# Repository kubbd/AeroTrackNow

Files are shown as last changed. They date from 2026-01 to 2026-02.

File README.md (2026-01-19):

# AeroTrackNow CanSat (Teensy 4.0)

## Project overview
This repo holds the flight and ground code for a guided CanSat with parafoil steering. It’s built around a Teensy 4.0 and a LoRa link, with a simple Python ground station on the PC.

## Flight system
The flight stack runs on a Teensy 4.0 and includes:

- Predictive landing guidance (steers to make predicted landing converge to target)
- GNSS (ZED-X20P) with RTK passthrough (Teensy forwards RTCM bytes to GNSS)
- LoRa (SX1262) bidirectional:
  - receive TARGET once
  - receive RTK continuously
  - send telemetry @ 1 Hz
- BMP280: pressure + temperature (and sink-rate estimate)
- BNO085: accelerometer + rotation vector (drop detection + heading)
- Dual-servo differential steering
- No buzzer

## Ground station
The ground station has two pieces that work together:

- **Ground radio node (Teensy + SX1262):** a USB-to-LoRa bridge.
- **PC ground station (Python):** reads telemetry, validates CRC, and shows the key numbers.

A Teensy is used on the ground because the SX1262 is an SPI radio that needs tight timing and interrupt handling. The Teensy handles those hardware details and exposes a simple USB serial link to the PC.

### USB serial ports (Teensy + optional RTK source)
Both the Teensy ground radio node and the RTK correction source plug into your laptop over USB. They show up as **two separate serial ports**, and you tell the ground station which is which with CLI flags.

- `--port` is **always** the Teensy ground radio node.
- `--rtk-port` is **optional** and is only for RTK correction input.
- RTK is optional — the system runs fine without it.

**USB device → CLI argument**

| USB device | CLI argument |
| --- | --- |
| Teensy ground radio node | `--port` |
| RTK correction source (optional) | `--rtk-port` |

**Examples**

Without RTK:
```
python3 ground_station_advanced.py --port /dev/ttyACM0 --target-lat 39.1234567 --target-lon -104.9876543 --target-alt 1850.0
```

With RTK:
```
python3 ground_station_advanced.py --port /dev/ttyACM0 --rtk-port /dev/ttyUSB0 --target-lat 39.1234567 --target-lon -104.9876543 --target-alt 1850.0
```

## Radio architecture
The ground radio node is intentionally “transparent.” It just moves bytes and doesn’t care about packet formats.

**What the firmware does:**
- Initialize SX1262 via RadioLib with the same pin mapping as flight hardware.
- Forward any USB serial bytes to LoRa (transparent transmit).
- Forward any LoRa packet bytes to USB (transparent receive).
- Operate non-blocking so serial and radio remain responsive.

**What the firmware does not do:**
- Parse packets or enforce application formats.
- Add CRC or message framing.
- Buffer or reorder payloads beyond RadioLib’s receive buffer.

**Data Flow Diagram (textual):**
PC (Python) ⇄ USB ⇄ Teensy 4.0 ⇄ SPI ⇄ SX1262 ⇄ Air ⇄ CanSat

## Folder structure
- `firmware/` – Teensy Arduino sketch
- `docs/` – pinout, telemetry, state machine docs
- `hardware/` – put KiCad files/netlists here

## How to get started
1. Skim `docs/TELEMETRY.md`, `docs/PINOUT.md`, and `docs/STATE_MACHINE.md` to understand the data formats and wiring.
2. Build and upload the flight firmware from `firmware/cansat_flight.ino`.
3. Build and upload the ground radio firmware from `firmware/ground_radio_teensy.ino`.
4. Run the Python ground station (`ground_station.py`) on your PC and point it at the Teensy USB port.

## Build instructions
1. Install required Arduino libraries:
   - RadioLib
   - SparkFun u-blox GNSS Arduino Library
   - Adafruit BMP280 Library
   - Adafruit BNO08x
2. Open `firmware/cansat_flight.ino` in Arduino IDE.
3. Select board: **Teensy 4.0**, then upload.

## Tuning parameters
Inside `firmware/cansat_flight.ino`:
- `RANGE_US` (servo throw) – start small, increase carefully
- `KP_TURN`, `MAX_TURN`
- `TERMINAL_HEIGHT_M`, `CAPTURE_RADIUS_M`
- `SERVO_TRIM` (parafoil trim) – change in steps of 0.01..0.02

Inside `cansat_flight_PRODUCTION_v2.ino`:
- `MAG_DECLINATION_DEG` – magnetic declination for the launch site (true-north alignment)
- `IMU_YAW_OFFSET_DEG` – IMU mounting yaw offset (0° if aligned to CanSat X-axis)
- `SINK_GNSS_BLEND_ALPHA` – blend factor for GNSS vertical velocity into sink rate
- `SERVO_RANGE_US`, `SERVO_MAX_RATE`, `SERVO_DEADBAND` – steering authority and responsiveness
- `FINAL_APPROACH_HEIGHT_M`, `FLARE_HEIGHT_M`, `TERMINAL_HEIGHT_M` – terminal guidance gates

**Why trim exists and how to tune it:**
Parafoils usually fly with a slight built-in bias. `SERVO_TRIM` lets you offset the neutral command so the canopy flies straight. Start at 0.0, do a short test glide, and nudge the trim by 0.01–0.02 until it tracks straight with neutral steering.

**How to disable guidance for testing:**
If you want to fly with no steering, set the guidance gains to zero (`KP_TURN = 0` and `MAX_TURN = 0`). The servos will stay neutral and the system will still log and transmit telemetry.

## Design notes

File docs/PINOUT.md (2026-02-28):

# PINOUT (Teensy 4.0)

These are the **actual Teensy pin numbers** (the leading number in the KiCad pin name).

## GNSS (ZED-X20P)
- GNSS UART: **Serial5**
- Teensy **RX** = **21** (GNSS TX1 → Teensy RX)
- Teensy **TX** = **20** (GNSS RX1 ← Teensy TX)
- TPS (optional) = **24** Currently unconnected
- RTKFIX (optional) = **25** Currently unconnected

## I2C (BNO085 + BMP280)
- SDA = **18**
- SCL = **19**

## LoRa (SX1262 / CORE1262-LF)
This module requires controlling the external RF switch using RXEN/TXEN (not DIO2/DIO3), and it may need a slow SPI clock (~500 kHz) for reliable operation.
- SCK = **13**
- MOSI = **11**
- MISO = **12**
- NSS/CS = **10**
- DIO1 = **7**
- RESET = **8**
- BUSY = **9**
- RXEN = **5**
- TXEN = **6**

## SD Card
- SPI shared with LoRa: **SCK/MOSI/MISO = 13 / 11 / 12**
- CS = **23**

## Servos
- Left servo PWM = **3**
- Right servo PWM = **4**

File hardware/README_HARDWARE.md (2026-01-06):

Put KiCad project files, PDFs, and netlists here.

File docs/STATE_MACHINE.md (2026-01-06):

# STATE MACHINE

## States
0. **BOOT**
   - Init sensors, radio, GNSS, SD
   - Servos neutral
   - Wait for TARGET packet

1. **WAIT_FOR_DROP**
   - Servos neutral
   - Wait for drop event
   - Drop detection is gated by descent (**sink_rate > 1.0 m/s**) to avoid rocket-launch false triggers.

2. **WAIT_FOR_STABLE_DESCENT**
   - Servos neutral
   - Wait until sink rate is stable (within band) continuously for ~2.5 s

3. **GUIDED_DESCENT**
   - Predictive guidance active
   - Compute predicted landing point and steer to reduce error

4. **TERMINAL**
   - Servos frozen neutral below terminal height and within capture radius
   - No more steering

5. **LANDED**
   - Servos neutral

## Transitions
- BOOT → WAIT_FOR_DROP: TARGET received
- WAIT_FOR_DROP → WAIT_FOR_STABLE_DESCENT: dropDetected() == true
- WAIT_FOR_STABLE_DESCENT → GUIDED_DESCENT: descentStable() == true
- GUIDED_DESCENT → TERMINAL: height < TERMINAL_HEIGHT_M && predicted error < CAPTURE_RADIUS_M
- TERMINAL → LANDED: landingDetected() == true

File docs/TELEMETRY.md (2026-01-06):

# TELEMETRY (CanSat → Ground)

**Rate:** 1 Hz  
**Transport:** LoRa (SX1262)  
**Encoding:** Binary struct + CRC16-CCITT

## Packet: TelemetryPacket (msgType = 0x03)

| Field | Type | Units / Scale |
|---|---|---|
| msgType | uint8 | 0x03 |
| time_ms | uint32 | milliseconds since boot |
| lat_e7 | int32 | latitude * 1e7 |
| lon_e7 | int32 | longitude * 1e7 |
| height_agl_dm | int16 | (GNSS_alt_MSL - target_alt_MSL) * 10 |
| pressure_hPa_x10 | uint16 | pressure (hPa) * 10 |
| temp_c_x10 | int16 | temperature (°C) * 10 |
| ground_speed_cms | uint16 | ground speed (m/s) * 100 |
| servo_left_x1000 | int16 | command -1000..1000 |
| servo_right_x1000 | int16 | command -1000..1000 |
| pred_lat_e7 | int32 | predicted landing latitude * 1e7 |
| pred_lon_e7 | int32 | predicted landing longitude * 1e7 |
| mission_state | uint8 | state enum |
| crc16 | uint16 | CRC16-CCITT over all prior bytes |

## Incoming packets (Ground → CanSat)

### TargetPacket (msgType = 0x01)
Sent once before drop.

| Field | Type | Units / Scale |
|---|---|---|
| msgType | uint8 | 0x01 |
| tgt_lat_e7 | int32 | latitude * 1e7 |
| tgt_lon_e7 | int32 | longitude * 1e7 |
| tgt_alt_cm | int32 | target altitude MSL (m) * 100 |
| crc16 | uint16 | CRC16-CCITT |

### RTK (msgType = 0x02)
- Byte stream of RTCM3 corrections.
- Teensy **forwards raw bytes** to the GNSS UART.

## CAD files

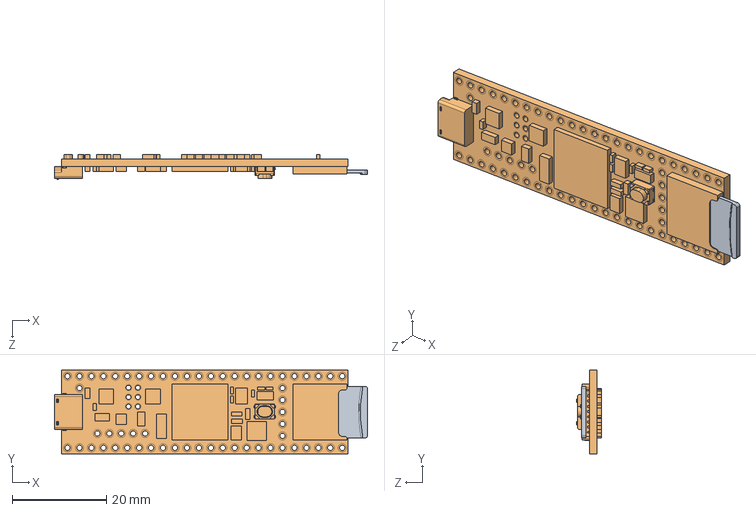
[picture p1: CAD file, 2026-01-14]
hardware/KiCad/Libaries/teensy.pretty-master/Teensy_4.1_Assembly.STEP
66.6 x 17.8 x 5.27 mm

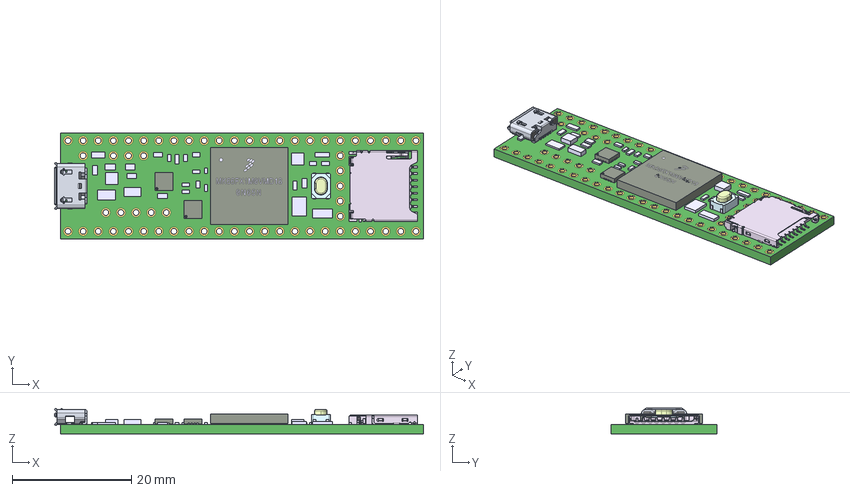
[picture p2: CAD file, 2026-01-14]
hardware/KiCad/Libaries/teensy.pretty-master/Teensy_3.5_3.6_Assembly.STEP
62.0 x 17.9 x 4.29 mm
switch
K66-CHIP
QFN-16 (3x3) Part1 x 2
QFN-16 (3x3) Part2 x 32
micro_usb_47346-0001
TEENSY_3_6_pcb
TEENSY_3_6_passives

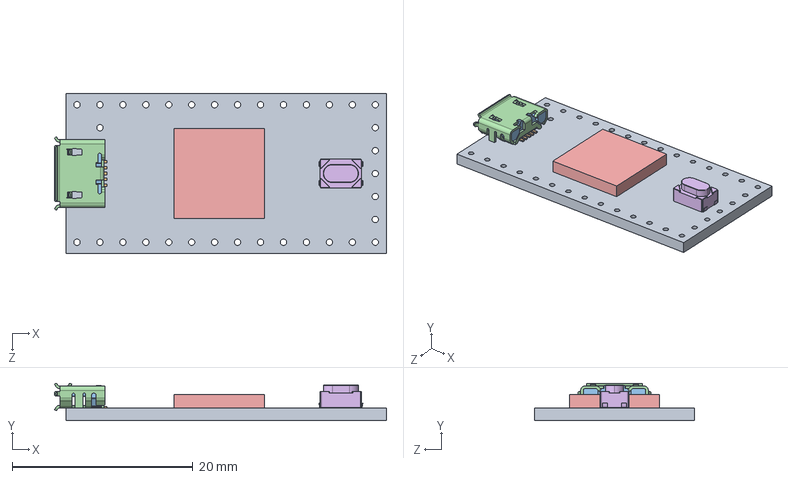
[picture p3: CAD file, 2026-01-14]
hardware/KiCad/Libaries/teensy.pretty-master/Teensy_4.0_Assembly.STEP
36.8 x 4.12 x 17.7 mm
Teensy_4.0_PCB
Micro USB-B Female 5Pin SMD
NXP iMXRT1062
SKRPACE010 v4

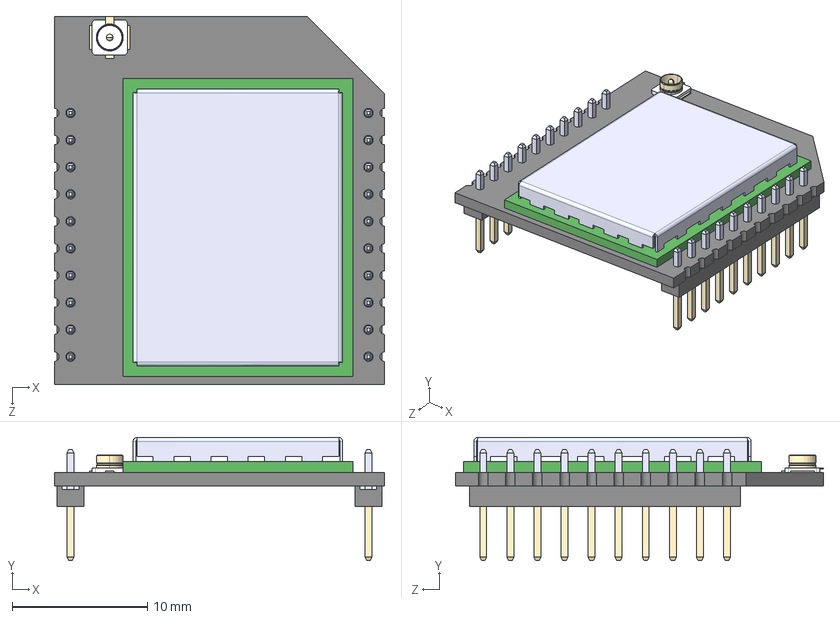
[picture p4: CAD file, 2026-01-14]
hardware/KiCad/Libaries/AS-RTK2B-MICRO-F9P-L1L2UFLTH-00/AS-RTK2B-MICRO-F9P-L1L2UFLTH-00.step
24.4 x 9.11 x 27.2 mm
Micro-PCB-00
ZED-F9P-00B-02--3DModel-STEP-56544.step
CONUFL001-SMD-T--3DModel-STEP-269445.step
_TMM-110-03-L-S_body.stp x 2
_TMM-110-03-L-S_pins1.stp x 2
_TMM-110-03-L-S_pins2.stp x 2

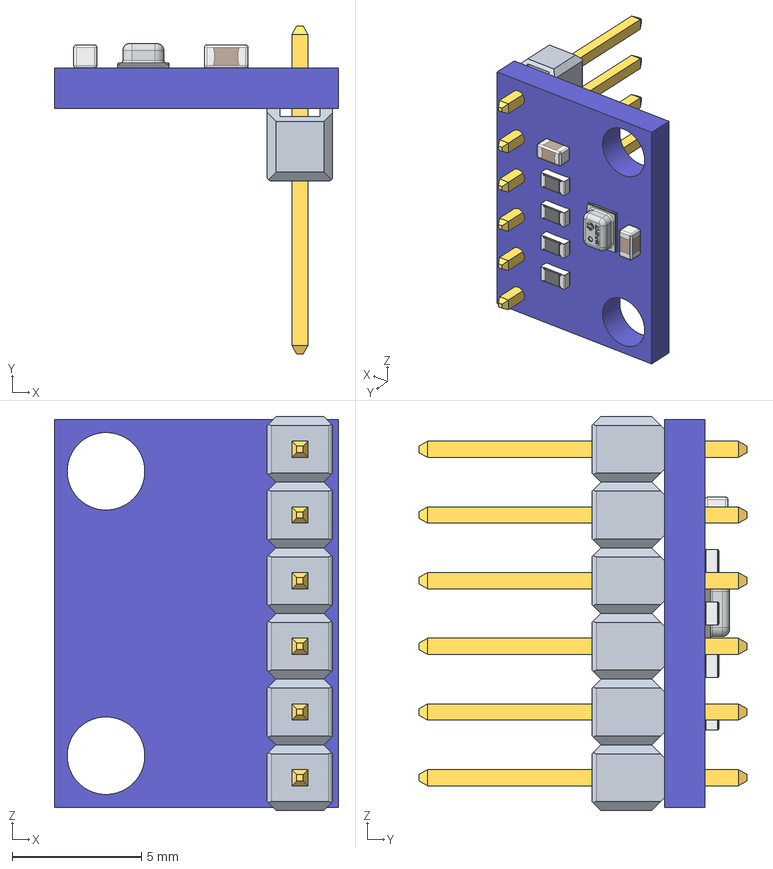
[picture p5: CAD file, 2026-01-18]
hardware/KiCad/Libaries/BMP280 OEM/bmp280_module.stp
11.0 x 12.7 x 15.2 mm

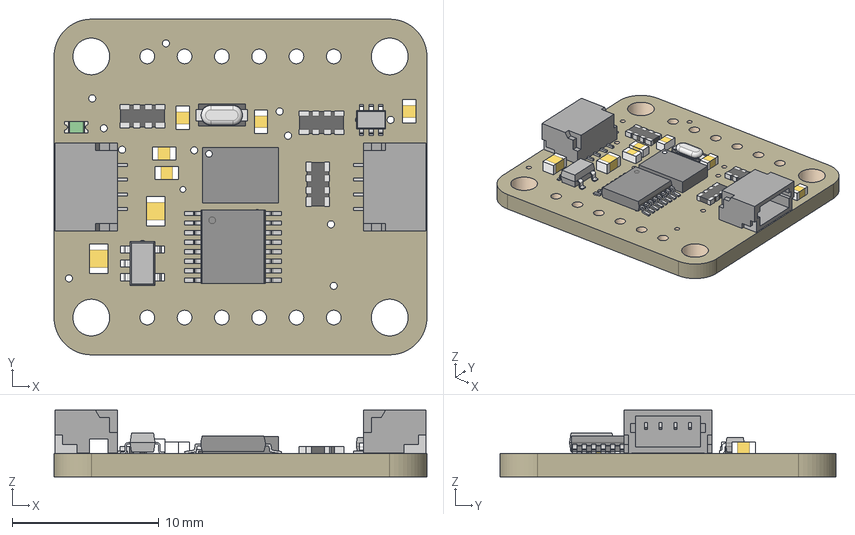
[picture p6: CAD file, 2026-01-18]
hardware/KiCad/Libaries/BNO085/4754 BNO085 STEMMA QT.step
25.4 x 22.9 x 4.53 mm
Board
10uF x 2
AP2112K-3.3
22pF x 5
10K x 3
BSS138
STEMMA_I2C_QT x 2
GREEN
BNO080
74AHC4050

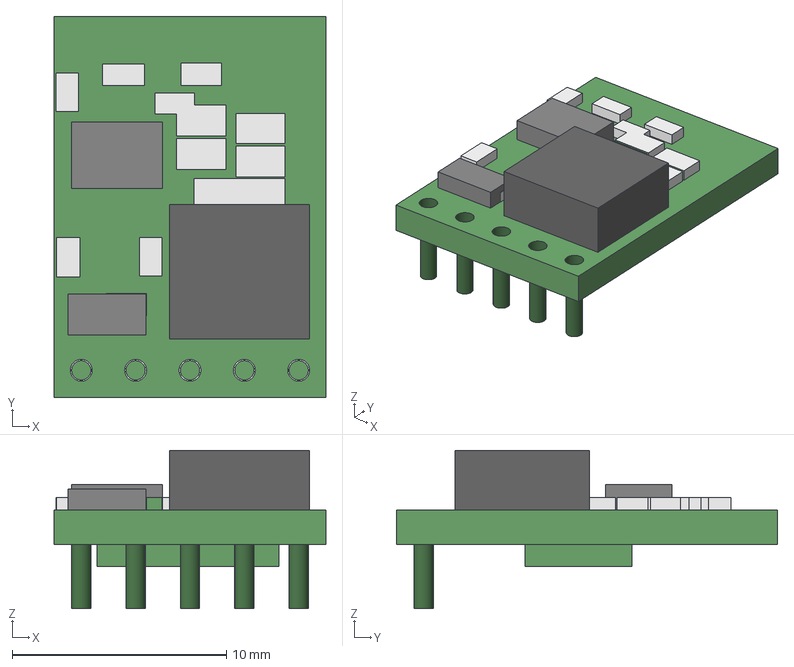
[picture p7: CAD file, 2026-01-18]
hardware/KiCad/Libaries/D24V10F3/D24V10F3.step
12.7 x 17.8 x 7.40 mm

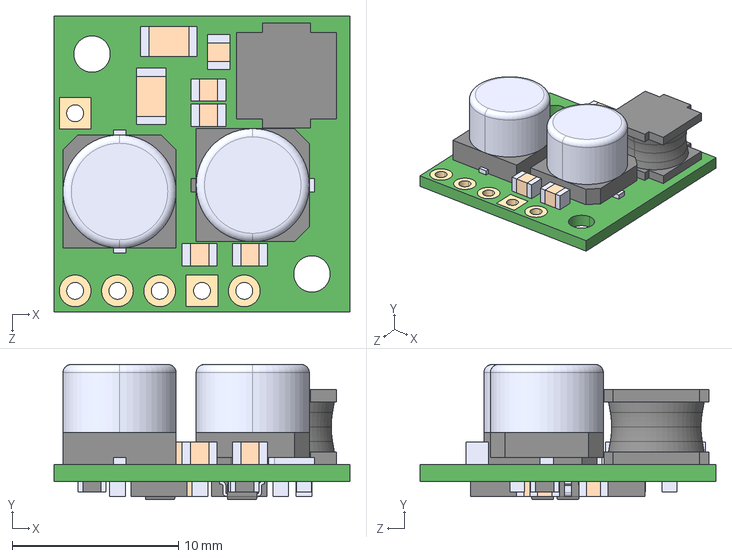
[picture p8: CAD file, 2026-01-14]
hardware/KiCad/Libaries/D24V22F5/D24V22F5.step
17.8 x 8.12 x 17.8 mm

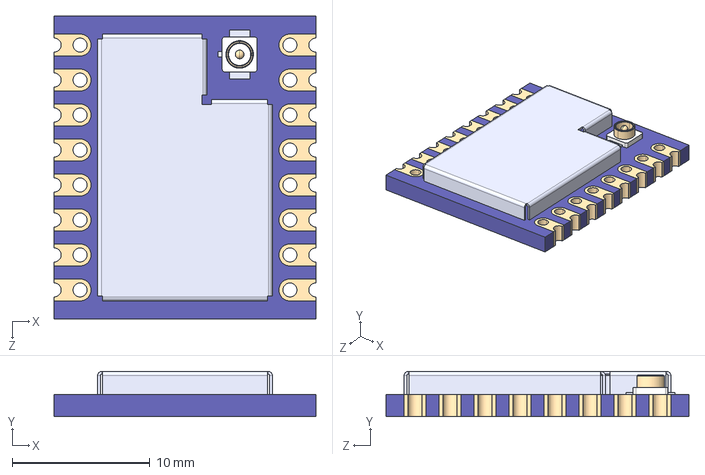
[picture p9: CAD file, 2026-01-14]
hardware/KiCad/Libaries/SX1262-LF/CORE1262-868M.step
19.0 x 3.27 x 22.0 mm

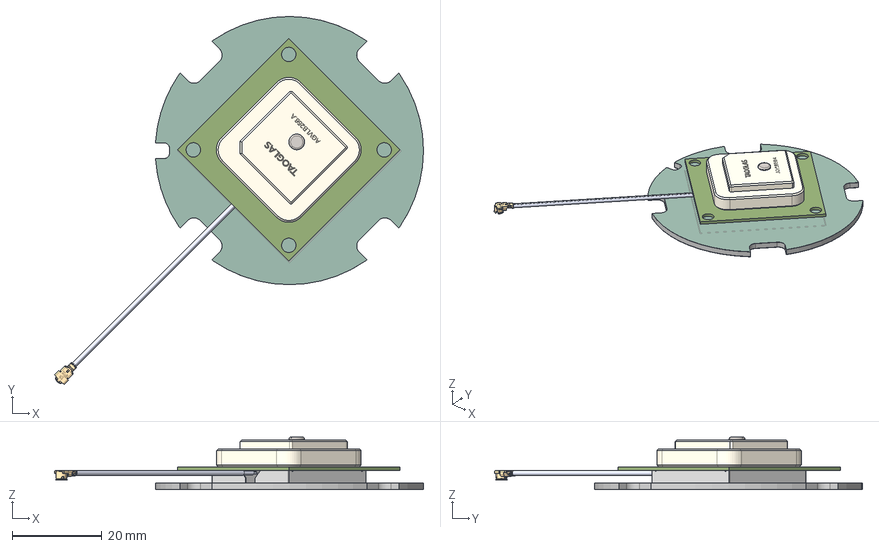
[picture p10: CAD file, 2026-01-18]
hardware/KiCad/PCB 0/PCB 0.step
82.0 x 81.8 x 11.7 mm
TG240188_AGVLB256_A_07_0100AO_BOARD
AGVLB256.A-Footprint-1_CMP-00131-2
000523D010000A_Shielding Case_D01
1.13 coaxial cable
STD IPEX.MHF1(113).Au
PCB 0_silkscreen
PCB 0_soldermask x 2
PCB 0_PCB

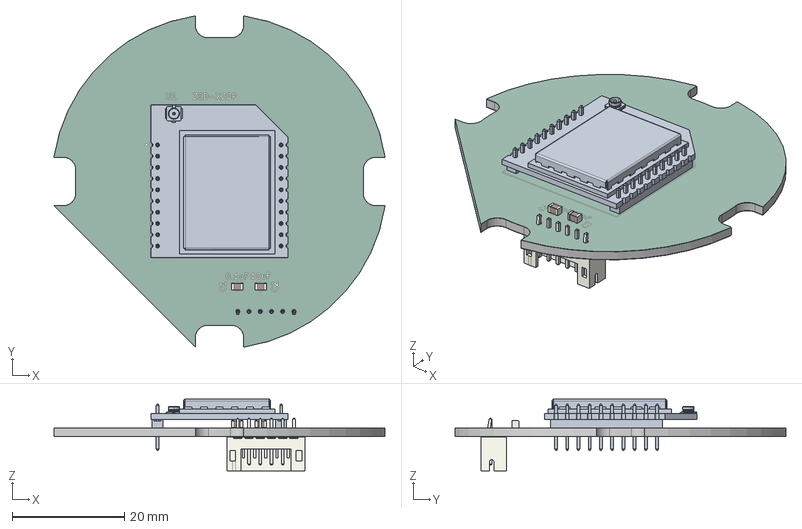
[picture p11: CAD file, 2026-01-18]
hardware/KiCad/PCB 1/PCB 1.step
59.0 x 59.0 x 12.8 mm
PCB 1 1.1.1
C_0805_2012Metric x 2
JST_PH_B6B-PH-K_1x06_P2.00mm_Vertical
PCB 1_silkscreen x 2
PCB 1_soldermask x 2
PCB 1_PCB

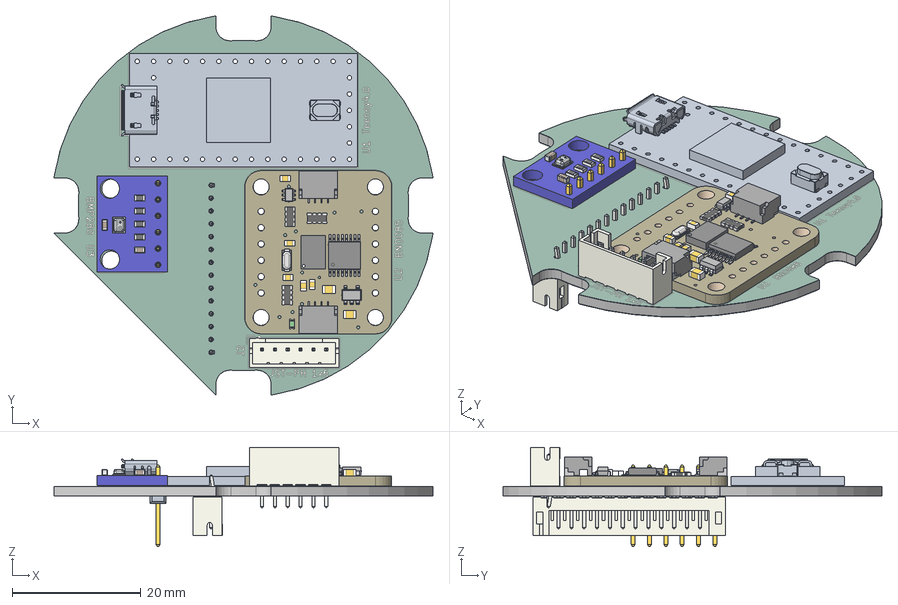
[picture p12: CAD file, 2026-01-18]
hardware/KiCad/PCB 2/PCB 2.step
59.0 x 59.0 x 15.4 mm
Board
0805-NO x 2
SOT23-5
0603-NO x 5
RESPACK_4X0603 x 3
SOT363
JST_SH4 x 2
CHIPLED_0603_NOOUTLINE
BNO080
XTAL3215
TSSOP16
Teensy_4.0_PCB
Micro USB-B Female 5Pin SMD
NXP iMXRT1062
SKRPACE010 v4
JST_PH_B6B-PH-K_1x06_P2.00mm_Vertical
JST_PH_B14B-PH-K_1x14_P2.00mm_Vertical
PCB 2_silkscreen x 2
PCB 2_soldermask x 2
PCB 2_PCB

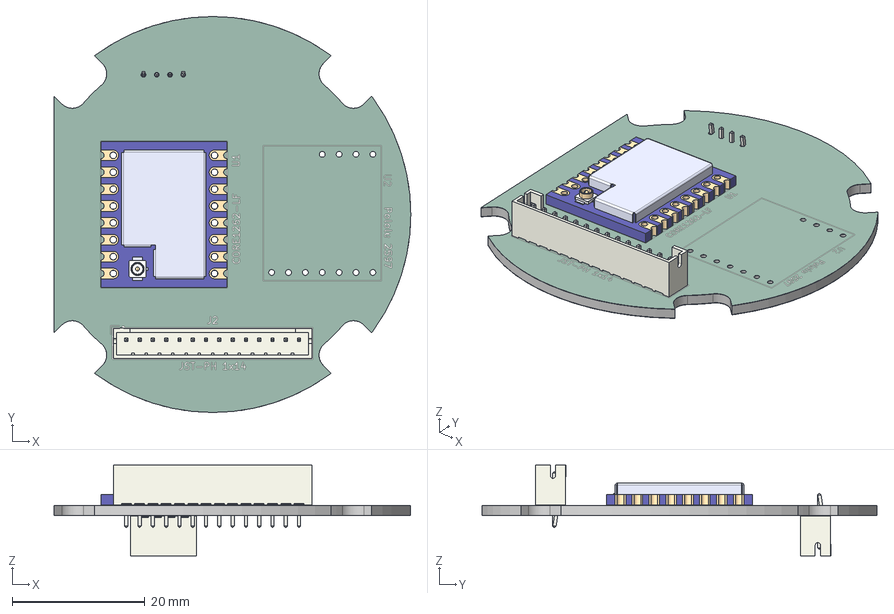
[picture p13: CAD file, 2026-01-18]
hardware/KiCad/PCB 3/PCB 3.step
53.7 x 59.6 x 13.7 mm
CORE1262-868M
JST_PH_B14B-PH-K_1x14_P2.00mm_Vertical
JST_PH_B4B-PH-K_1x04_P2.00mm_Vertical
PCB 3_silkscreen x 2
PCB 3_soldermask x 2
PCB 3_PCB

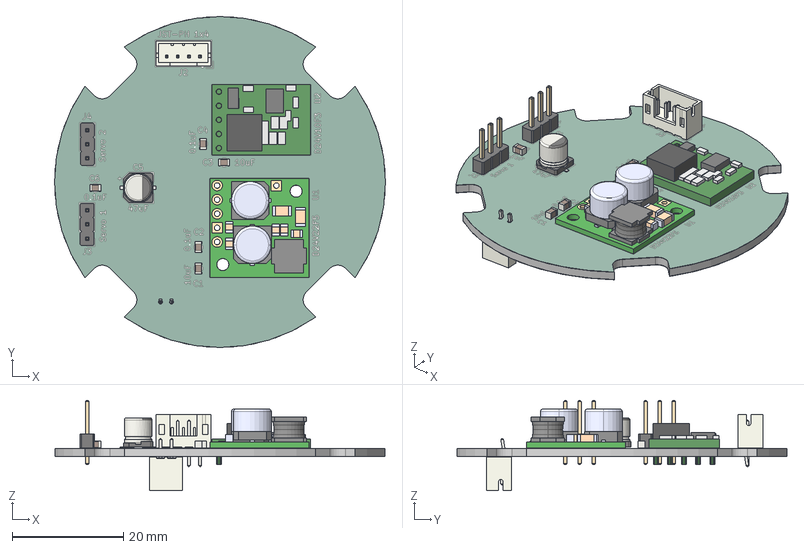
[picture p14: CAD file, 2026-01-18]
hardware/KiCad/PCB 4/PCB 4.step
59.6 x 59.6 x 16.2 mm
JST_PH_B4B-PH-K_1x04_P2.00mm_Vertical
C_0805_2012Metric x 5
PinHeader_1x03_P2.54mm_Vertical x 2
D24V22F5
CP_Elec_5x5.4
D24V10F3
JST_PH_B2B-PH-K_1x02_P2.00mm_Vertical
PCB 4_silkscreen x 2
PCB 4_soldermask x 2
PCB 4_PCB

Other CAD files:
hardware/KiCad/Libaries/D24V10F3/D24V10F3.stp

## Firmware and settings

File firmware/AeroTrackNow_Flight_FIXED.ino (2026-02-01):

#include <Arduino.h>
#include <Wire.h>
#include <Servo.h>
#include <SD.h>
// GNSS (u-blox)
#include <SparkFun_u-blox_GNSS_Arduino_Library.h>
// Sensors
#include <Adafruit_BMP280.h>
#include <Adafruit_BNO08x.h>
// LoRa (SX1262)
#include <RadioLib.h>
// ===================== HARDWARE PINOUT =====================
// From your Pinout.MD - DO NOT CHANGE unless hardware changes
static constexpr int PIN_GNSS_RX = 21;  // Serial5 RX
static constexpr int PIN_GNSS_TX = 20;  // Serial5 TX
static constexpr int PIN_GNSS_TPS = 24;  // optional
static constexpr int PIN_GNSS_RTKFIX = 25;  // optional
static constexpr int PIN_I2C_SDA = 18;
static constexpr int PIN_I2C_SCL = 19;
static constexpr int PIN_LORA_CS = 10;
static constexpr int PIN_LORA_DIO1 = 7;
static constexpr int PIN_LORA_RESET = 8;
static constexpr int PIN_LORA_BUSY = -1;  // not connected
static constexpr int PIN_SD_CS = 23;
static constexpr int PIN_SERVO_LEFT = 3;
static constexpr int PIN_SERVO_RIGHT = 4;
// ===================== PARAFOIL PARAMETERS =====================
// Update after real flight tests and canopy changes.
// Geometry from provided stencil data.
static constexpr float PARAFOIL_AREA_M2 = 0.141f;  // Active lift area
static constexpr float PARAFOIL_GLIDE_RATIO = 2.0f;
static constexpr float NOMINAL_SINK_RATE = 5.5f;  // m/s (positive down)
static constexpr float NOMINAL_AIRSPEED = NOMINAL_SINK_RATE * PARAFOIL_GLIDE_RATIO;
// Brake response curves (replace with measured data after tests)
static constexpr float BRAKE_TABLE[] = {0.0f, 0.25f, 0.5f, 0.75f, 1.0f};
static constexpr float SINK_RATE_TABLE[] = {5.5f, 5.9f, 6.4f, 6.9f, 7.2f};
static constexpr float GLIDE_RATIO_TABLE[] = {2.0f, 1.9f, 1.7f, 1.55f, 1.4f};
static constexpr float TURN_RATE_SCALE_TABLE[] = {1.0f, 1.05f, 1.1f, 1.15f, 1.2f};
static constexpr int BRAKE_TABLE_SIZE = sizeof(BRAKE_TABLE) / sizeof(BRAKE_TABLE[0]);
static constexpr float SERVO_TIME_CONSTANT_S = 0.10f;  // ✓ FIXED: MG92B actual response time
// Seeded wind profile (disabled by default; real-time wind estimation is preferred).
static constexpr bool USE_SEEDED_WIND_PROFILE = false;
static constexpr float WARSAW_PROFILE_MAX_ALT_M = 2000.0f;
static constexpr float WARSAW_WIND_DIR_DEG[] = {0.0f};
static constexpr float WARSAW_WIND_SPD_MPS[] = {0.0f};
static constexpr int WARSAW_WIND_BINS = sizeof(WARSAW_WIND_SPD_MPS) / sizeof(WARSAW_WIND_SPD_MPS[0]);
// ===================== CONTROL PARAMETERS =====================
static constexpr float KP_HEADING = 0.9f;
static constexpr float KI_HEADING = 0.05f;
static constexpr float KD_HEADING = 0.12f;
static constexpr float MAX_BANK_ANGLE_RAD = 0.48f;  // ~27.5°
static constexpr float MAX_TURN_RATE_RAD_S = 0.8f;
static constexpr float HEADING_JUMP_MAX_RAD = 1.2f;
static constexpr uint32_t HEADING_JUMP_MAX_DT_MS = 150;
// ⚠️⚠️⚠️ MANDATORY CALIBRATION BEFORE FIRST FLIGHT ⚠️⚠️⚠️
// Set HEADING_CALIBRATION_MODE = true, upload, point North, read Serial Monitor
// Calculate: HEADING_OFFSET_RAD = (0.0 - measured_value)
// Update HEADING_OFFSET_RAD below, set HEADING_CALIBRATION_MODE = false, re-upload
static constexpr bool HEADING_CALIBRATION_MODE = false;
static constexpr float HEADING_OFFSET_RAD = 0.0f;  // ⚠️ CALIBRATE THIS!
static constexpr float MIN_GROUND_SPEED_FOR_TRACK = 0.5f;
static constexpr float HEADING_CONFIDENCE_MAX_DELTA_RAD = 0.35f;
static constexpr float HEADING_CONFIDENCE_MIN_FOR_WIND = 0.4f;
static constexpr uint32_t HEADING_CONFIDENCE_MAX_DT_MS = 300;
// Servo parameters
static constexpr float SERVO_TRIM = 0.0f;
static constexpr int SERVO_NEUTRAL_US = 1500;
static constexpr int SERVO_RANGE_US = 300;
static constexpr float SERVO_MAX_RATE = 2.0f;  // Max change per second
static constexpr float SERVO_DEADBAND = 0.02f;
// State machine altitudes
static constexpr float FINAL_APPROACH_HEIGHT_M = 30.0f;
static constexpr float FLARE_HEIGHT_M = 3.0f;
static constexpr float TERMINAL_HEIGHT_M = 1.0f;
static constexpr float TERMINAL_HOMING_HEIGHT_M = 50.0f;
static constexpr float CAPTURE_RADIUS_M = 1.0f;
static constexpr float CAPTURE_RADIUS_GNSS_M = 5.0f;
static constexpr float CAPTURE_RADIUS_POOR_M = 10.0f;
// Stability detection
static constexpr float STABLE_SINK_MIN = 4.5f;
static constexpr float STABLE_SINK_MAX = 6.5f;
static constexpr uint32_t STABLE_HOLD_MS = 1500;
// Drop detection
static constexpr float DROP_ACCEL_SPIKE = 8.0f;
static constexpr int DROP_DEBOUNCE_COUNT = 3;
// Sink rate filtering
static constexpr uint32_t BARO_UPDATE_INTERVAL_MS = 200;  // 5 Hz
static constexpr float SINK_FILTER_ALPHA = 0.2f;
static constexpr float SINK_RATE_MIN = 3.0f;
static constexpr float SINK_RATE_MAX = 9.0f;
// Wind estimation
static constexpr float WIND_FILTER_ALPHA = 0.03f;
static constexpr float MAX_WIND_ESTIMATE = 18.0f;
static constexpr float MAX_WIND_UPDATE_DELTA = 8.0f;  // ✓ FIXED: Allow Warsaw turbulence
static constexpr float MAX_WIND_LAYER_DELTA = 10.0f;  // ✓ FIXED: Allow wind shear
static constexpr float MIN_WIND_UPDATE_ALT_M = 10.0f;
static constexpr float WIND_LAYER_STEP_M = 25.0f;
static constexpr int WIND_LAYER_COUNT = 80;
static constexpr float WIND_LAYER_DECAY_PER_S = 0.005f;  // ✓ FIXED: 3 min time constant
static constexpr float MAX_WIND_FOR_GUIDANCE = 8.0f;  // Abort guidance above this (m/s)
static constexpr float WIND_GAIN_REDUCTION_START = 4.0f;
static constexpr float WIND_GAIN_MIN_FACTOR = 0.6f;
static constexpr float WIND_LAYER_SMOOTH_ALPHA = 0.12f;
static constexpr float WIND_LAYER_BLEND_RADIUS = 2;
// Gust detection
static constexpr float GUST_SPEED_SPIKE_MPS = 3.0f;
static constexpr uint32_t GUST_HOLD_MS = 1500;
static constexpr float GUST_GAIN_FACTOR = 0.7f;
// Glide-slope management
static constexpr float GLIDESLOPE_TARGET_SINK_HIGH = 5.6f;
static constexpr float GLIDESLOPE_TARGET_SINK_LOW = 4.6f;
static constexpr float GLIDESLOPE_TARGET_HIGH_ALT_M = 200.0f;
static constexpr float GLIDESLOPE_TARGET_LOW_ALT_M = 20.0f;
static constexpr float GLIDESLOPE_MAX_BRAKE = 0.35f;
static constexpr float GLIDESLOPE_KP = 0.12f;
static constexpr float GLIDESLOPE_KI = 0.02f;
// Lateral velocity damping (non-terminal)
static constexpr float LATERAL_DAMPING_GAIN = 0.15f;
// Safety gating
static constexpr float MAX_EKF_SPEED_MPS = 25.0f;
static constexpr float MIN_GNSS_SATS_FOR_GUIDANCE = 6;
static constexpr float MAX_GNSS_AGE_MS = 1500;
// MPC parameters (short horizon + dynamics)
static constexpr int MPC_HORIZON = 12;
static constexpr int MPC_SAMPLES = 21;
static constexpr float MPC_CONTROL_WEIGHT = 0.15f;
static constexpr float APPROACH_GAIN = 1.8f;
// Terminal cross-track controller
static constexpr float KP_CROSSTRACK = 0.07f;
static constexpr float KD_CROSSTRACK = 0.18f;
static constexpr float MAX_CROSSTRACK_CMD = 1.0f;
static constexpr float HEADING_GAIN_HIGH_ALT = 0.7f;
static constexpr float HEADING_GAIN_LOW_ALT = 1.25f;
static constexpr float HEADING_GAIN_HIGH_ALT_M = 150.0f;
static constexpr float HEADING_GAIN_LOW_ALT_M = 20.0f;
static constexpr float CROSSTRACK_GAIN_HIGH_ALT = 0.8f;
static constexpr float CROSSTRACK_GAIN_LOW_ALT = 1.3f;
static constexpr float CROSSTRACK_GAIN_HIGH_ALT_M = 60.0f;
static constexpr float CROSSTRACK_GAIN_LOW_ALT_M = 10.0f;
// EKF process/measurement noise (tune after data collection)
static constexpr float EKF_Q_POS = 2.0f;
static constexpr float EKF_Q_VEL = 1.0f;
static constexpr float EKF_Q_WIND = 0.5f;
static constexpr float EKF_R_POS = 3.5f;
static constexpr float EKF_R_VEL = 1.2f;
static constexpr float EKF_R_WIND = 2.0f;
// ===================== RADIO SETTINGS =====================
static constexpr float LORA_FREQ_MHZ = 433.0f;
static constexpr int LORA_TX_DBM = 14;
static constexpr uint32_t TELEMETRY_PERIOD_MS = 1000;
// ===================== TELEMETRY PACKET =====================
#pragma pack(push, 1)
struct TelemetryPacket {
  uint8_t msgType;  // 0x03
  uint32_t time_ms;
  int32_t lat_e7;
  int32_t lon_e7;
  int16_t height_agl_dm;  // meters * 10
  uint16_t pressure_hPa_x10;
  int16_t temp_c_x10;
  uint16_t ground_speed_cms;
  int16_t servo_left_x1000;
  int16_t servo_right_x1000;
  int32_t pred_lat_e7;
  int32_t pred_lon_e7;
  int16_t wind_north_cms;
  int16_t wind_east_cms;
  int16_t heading_deg_x10;
  uint16_t heading_confidence_x1000;
  uint16_t wind_rejects;
  uint16_t wind_layer_rejects;
  uint8_t mission_state;
  uint16_t crc16;
};
#pragma pack(pop)
// ===================== INCOMING PACKETS =====================
#pragma pack(push, 1)
struct TargetPacket {
  uint8_t msgType;  // 0x01
  int32_t tgt_lat_e7;
  int32_t tgt_lon_e7;
  int32_t tgt_alt_cm;  // meters MSL * 100
  uint16_t crc16;
};
#pragma pack(pop)
// Message types
static constexpr uint8_t MSG_TARGET = 0x01;
static constexpr uint8_t MSG_RTK = 0x02;
static constexpr uint8_t MSG_TELEMETRY = 0x03;
// ===================== STATE MACHINE =====================
enum MissionState : uint8_t {
  BOOT = 0,
  WAIT_FOR_DROP,
  WAIT_FOR_STABLE_DESCENT,
  GUIDED_DESCENT,
  FINAL_APPROACH,
  TERMINAL_HOMING,
  FLARE,
  TERMINAL,
  LANDED
};
MissionState state = BOOT;
// ===================== GLOBAL OBJECTS =====================
SFE_UBLOX_GNSS gnss;
Adafruit_BMP280 bmp;
Adafruit_BNO08x bno08x(-1);
sh2_SensorValue_t bnoValue;
SX1262 radio = new Module(PIN_LORA_CS, PIN_LORA_DIO1, PIN_LORA_RESET, PIN_LORA_BUSY);
Servo servoL, servoR;
File logFile;
// ===================== STATE VARIABLES =====================
// Target
bool targetReceived = false;
double target_lat = 0.0;
double target_lon = 0.0;
double target_alt_msl = 0.0;
// GNSS live
double lat = 0.0, lon = 0.0;
double gnss_alt_msl = 0.0;
double ground_speed = 0.0;
double ground_track_rad = 0.0;
bool ground_track_valid = false;
double gnss_vertical_velocity = 0.0;
// Heading estimate (from BNO08x)
double heading_rad = 0.0;
bool heading_valid = false;
uint32_t last_heading_ms = 0;
double last_heading_rad = 0.0;
float heading_confidence = 0.0f;
// IMU accel cache
float imu_ax = 0.0f;
float imu_ay = 0.0f;
float imu_az = 0.0f;
bool imu_accel_valid = false;
uint32_t last_imu_ms = 0;
// GNSS quality
uint8_t gnss_fix_type = 0;
uint8_t gnss_satellites = 0;
uint32_t gnss_h_accuracy_mm = 9999;
uint32_t gnss_v_accuracy_mm = 9999;
uint32_t last_gnss_update = 0;
// Baro live
double pressure_hPa = 0.0;
double temp_c = 0.0;
double baro_alt_msl = 0.0;
double last_baro_alt = 0.0;
uint32_t last_baro_ms = 0;
// Fused altitude
double fused_alt_msl = 0.0;
double fused_alt_velocity = 0.0;
// Sink rate (filtered)
double sink_rate_raw = NOMINAL_SINK_RATE;
double sink_rate_filtered = NOMINAL_SINK_RATE;
double sink_rate_gnss = NOMINAL_SINK_RATE;
// Wind estimation
double wind_north = 0.0;
double wind_east = 0.0;
double wind_speed = 0.0;
double wind_layer_north[WIND_LAYER_COUNT]{};
double wind_layer_east[WIND_LAYER_COUNT]{};
uint32_t wind_layer_ms[WIND_LAYER_COUNT]{};
bool gust_active = false;
uint32_t gust_until_ms = 0;
double last_wind_speed = 0.0;
uint16_t wind_update_rejects = 0;
uint16_t wind_layer_rejects = 0;
// Glide-slope controller
float glide_integral = 0.0f;
// Prediction
double pred_lat = 0.0, pred_lon = 0.0;
double predicted_error_m = 999.0;
// Servo state
float cmdL_current = 0.0f;
float cmdR_current = 0.0f;
float cmdL_target = 0.0f;
float cmdR_target = 0.0f;
uint32_t last_servo_update_ms = 0;
// Drop detection
int drop_spike_count = 0;
// Stability detection
uint32_t stableStartMs = 0;
// Timers
uint32_t lastTelemetryMs = 0;
uint32_t loop_start_ms = 0;
// Sea level pressure (for baro altitude)
double sea_level_pressure_hpa = 1013.25;
bool sea_level_calibrated = false;
// Controller state
double heading_error_integral = 0.0;
double last_heading_error = 0.0;
uint32_t last_heading_update_ms = 0;
// Navigation frame
double origin_lat = 0.0;
double origin_lon = 0.0;
bool origin_set = false;
struct StateEstimate {
  double north_m = 0.0;
  double east_m = 0.0;
  double v_north = 0.0;
  double v_east = 0.0;
  bool initialized = false;
};
StateEstimate nav_est{};
struct EKFState {
  double north_m = 0.0;
  double east_m = 0.0;
  double v_north = 0.0;
  double v_east = 0.0;
  double wind_north = 0.0;
  double wind_east = 0.0;
  bool initialized = false;
};
EKFState ekf_state{};
// ===================== UTILITY FUNCTIONS =====================
static uint16_t crc16_ccitt(const uint8_t *data, size_t len) {
  uint16_t crc = 0xFFFF;
  for (size_t i = 0; i < len; i++) {
    crc ^= (uint16_t)data[i] << 8;
    for (int b = 0; b < 8; b++) {
      if (crc & 0x8000) crc = (crc << 1) ^ 0x1021;
      else crc <<= 1;
    }
  }
  return crc;
}
static inline double metersPerDegLat() {
  return 111111.0;
}
static inline double metersPerDegLon(double lat_deg) {
  return 111111.0 * cos(lat_deg * DEG_TO_RAD);
}
static double distanceMeters(double lat1, double lon1, double lat2, double lon2) {
  const double R = 6371000.0;
  double dLat = (lat2 - lat1) * DEG_TO_RAD;
  double dLon = (lon2 - lon1) * DEG_TO_RAD;
  double a = sin(dLat / 2) * sin(dLat / 2) +
             cos(lat1 * DEG_TO_RAD) * cos(lat2 * DEG_TO_RAD) * sin(dLon / 2) * sin(dLon / 2);
  double c = 2 * atan2(sqrt(a), sqrt(1 - a));
  return R * c;
}
static double bearingRad(double fromLat, double fromLon, double toLat, double toLon) {
  double dLat = (toLat - fromLat);
  double dLon = (toLon - fromLon) * cos(fromLat * DEG_TO_RAD);
  return atan2(dLon, dLat);
}
static float clampf(float v, float lo, float hi) {
  return (v < lo) ? lo : (v > hi) ? hi : v;
}
static double clampd(double v, double lo, double hi) {
  return (v < lo) ? lo : (v > hi) ? hi : v;
}
static float lerpf(float a, float b, float t) {
  return a + (b - a) * t;
}
static float lookupTable(const float *x, const float *y, int size, float value) {
  if (size <= 0) return 0.0f;
  if (value <= x[0]) return y[0];
  if (value >= x[size - 1]) return y[size - 1];
  for (int i = 0; i < size - 1; i++) {
    if (value >= x[i] && value <= x[i + 1]) {
      float t = (value - x[i]) / (x[i + 1] - x[i]);
      return lerpf(y[i], y[i + 1], t);
    }
  }
  return y[size - 1];
}
static float altitudeGain(double height_agl,
                          float high_alt_gain,
                          float low_alt_gain,
                          float high_alt_m,
                          float low_alt_m) {
  if (height_agl >= high_alt_m) return high_alt_gain;
  if (height_agl <= low_alt_m) return low_alt_gain;
  if (fabs(high_alt_m - low_alt_m) < 0.001f) return low_alt_gain;
  float t = (float)((height_agl - low_alt_m) / (high_alt_m - low_alt_m));
  return lerpf(low_alt_gain, high_alt_gain, t);
}
static float wrapAngle(float angle) {
  while (angle > PI) angle -= TWO_PI;
  while (angle < -PI) angle += TWO_PI;
  return angle;
}
static float wrapAngleDeg(float angle) {
  while (angle >= 360.0f) angle -= 360.0f;
  while (angle < 0.0f) angle += 360.0f;
  return angle;
}
static double getHeadingRad() {
  if (heading_valid && (millis() - last_heading_ms) < 1000) {
    return heading_rad;
  }
  if (ground_track_valid) {
    return ground_track_rad;
  }
  return last_heading_rad;
}
static bool isHeadingFresh() {
  return heading_valid && (millis() - last_heading_ms) < 1000;
}
static float getHeadingConfidence() {
  if (!heading_valid) return 0.0f;
  uint32_t age_ms = millis() - last_heading_ms;
  if (age_ms >= HEADING_CONFIDENCE_MAX_DT_MS) return 0.0f;
  float age_factor = 1.0f - (float)age_ms / (float)HEADING_CONFIDENCE_MAX_DT_MS;
  return clampf(heading_confidence * age_factor, 0.0f, 1.0f);
}
static float normalizeBrake(float left, float right) {
  float sym = 0.5f * (fabs(left) + fabs(right));
  return clampf(sym, 0.0f, 1.0f);
}
static float brakeToSinkRate(float brake) {
  float sink = lookupTable(BRAKE_TABLE, SINK_RATE_TABLE, BRAKE_TABLE_SIZE, brake);
  return clampf(sink, SINK_RATE_MIN, SINK_RATE_MAX);
}
static float brakeToGlideRatio(float brake) {
  float ratio = lookupTable(BRAKE_TABLE, GLIDE_RATIO_TABLE, BRAKE_TABLE_SIZE, brake);
  return clampf(ratio, 0.8f, 3.5f);
}
static float brakeToTurnRateScale(float brake) {
  float scale = lookupTable(BRAKE_TABLE, TURN_RATE_SCALE_TABLE, BRAKE_TABLE_SIZE, brake);
  return clampf(scale, 0.5f, 2.0f);
}
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
void loop() {
  loop_start_ms = millis();
  updateIMU();
  updateBMP280();
  updateGNSS();
  pollLoRa();
  switch (state) {
    case BOOT:
      setServosNormalized(0, 0);
      if (targetReceived) {
        Serial.println("STATE: BOOT -> WAIT_FOR_DROP");
        state = WAIT_FOR_DROP;
      }
      break;
    case WAIT_FOR_DROP:
      setServosNormalized(0, 0);
      if (dropDetected()) {
        Serial.println("STATE: WAIT_FOR_DROP -> WAIT_FOR_STABLE_DESCENT");
        state = WAIT_FOR_STABLE_DESCENT;
      }
      break;
    case WAIT_FOR_STABLE_DESCENT:
      setServosNormalized(0, 0);
      if (descentStable()) {
        Serial.println("STATE: WAIT_FOR_STABLE_DESCENT -> GUIDED_DESCENT");
        resetGuidanceIntegrators();
        state = GUIDED_DESCENT;
      }
      break;
    case GUIDED_DESCENT: {
      if (!targetReceived) {
        setServosNormalized(0, 0);
        break;
      }
      if (!guidanceSafe()) {
        resetGuidanceIntegrators();
        setServosNormalized(0, 0);
        break;
      }
      runPredictiveGuidance();
      double height_agl = fused_alt_msl - target_alt_msl;
      if (height_agl < FINAL_APPROACH_HEIGHT_M) {
        Serial.println("STATE: GUIDED_DESCENT -> FINAL_APPROACH");
        resetGuidanceIntegrators();
        state = FINAL_APPROACH;
        break;
      }
      setServosNormalized(cmdL_target, cmdR_target);
      break;
    }
    case FINAL_APPROACH: {
      if (!targetReceived) {
        setServosNormalized(0, 0);
        break;
      }
      if (!guidanceSafe()) {
        resetGuidanceIntegrators();
        setServosNormalized(0, 0);
        break;
      }
      runPredictiveGuidance();
      double height_agl = fused_alt_msl - target_alt_msl;
      float capture_radius = getDynamicCaptureRadius();
      if (height_agl < TERMINAL_HOMING_HEIGHT_M) {
        Serial.println("STATE: FINAL_APPROACH -> TERMINAL_HOMING");
        resetGuidanceIntegrators();
        state = TERMINAL_HOMING;
        break;
      }
      if (height_agl < FLARE_HEIGHT_M) {
        Serial.println("STATE: FINAL_APPROACH -> FLARE");
        state = FLARE;
        break;
      }
      if (height_agl < TERMINAL_HEIGHT_M && predicted_error_m < capture_radius) {
        Serial.println("STATE: FINAL_APPROACH -> TERMINAL");
        cmdL_target = 0.0f;
        cmdR_target = 0.0f;
        state = TERMINAL;
        break;
      }
      setServosNormalized(cmdL_target, cmdR_target);
      break;
    }
    case TERMINAL_HOMING: {
      if (!targetReceived) {
        setServosNormalized(0, 0);
        break;
      }
      if (!guidanceSafe()) {
        resetGuidanceIntegrators();
        setServosNormalized(0, 0);
        break;
      }
      estimateWind();
      double height_agl = fused_alt_msl - target_alt_msl;
      float capture_radius = getDynamicCaptureRadius();
      if (height_agl < FLARE_HEIGHT_M) {
        Serial.println("STATE: TERMINAL_HOMING -> FLARE");
        state = FLARE;
        break;
      }
      if (height_agl < TERMINAL_HEIGHT_M && predicted_error_m < capture_radius) {
        Serial.println("STATE: TERMINAL_HOMING -> TERMINAL");
        cmdL_target = 0.0f;
        cmdR_target = 0.0f;
        state = TERMINAL;
        break;
      }
      if (origin_set && ekf_state.initialized) {
        double tgt_n = 0.0;
        double tgt_e = 0.0;
        latLonToNE(target_lat, target_lon, tgt_n, tgt_e);
        double err_n = tgt_n - ekf_state.north_m;
        double err_e = tgt_e - ekf_state.east_m;
        double distance = sqrt(err_n * err_n + err_e * err_e);
        predicted_error_m = distance;
        double heading = getHeadingRad();
        double err_lat = -err_n * sin(heading) + err_e * cos(heading);
        double vel_lat = -ekf_state.v_north * sin(heading) + ekf_state.v_east * cos(heading);
        float cross_gain = altitudeGain(height_agl,
                                        CROSSTRACK_GAIN_HIGH_ALT,
                                        CROSSTRACK_GAIN_LOW_ALT,
                                        CROSSTRACK_GAIN_HIGH_ALT_M,
                                        CROSSTRACK_GAIN_LOW_ALT_M);
        float cross_cmd = (KP_CROSSTRACK * cross_gain * (float)err_lat) +
                          (KD_CROSSTRACK * cross_gain * (float)vel_lat);
        cross_cmd = clampf(cross_cmd, -MAX_CROSSTRACK_CMD, MAX_CROSSTRACK_CMD);
        double desired_bearing = atan2(err_e, err_n);
        float heading_cmd = computeHeadingControl(desired_bearing,
                                                  APPROACH_GAIN * 0.7f * cross_gain);
        float turn_cmd = clampf(heading_cmd + cross_cmd, -1.0f, 1.0f);
        float glide_cmd = applyGlideSlope(height_agl);
        cmdL_target = clampf(-turn_cmd + glide_cmd, -1.0f, 1.0f);
        cmdR_target = clampf(turn_cmd + glide_cmd, -1.0f, 1.0f);
      } else {
        runPredictiveGuidance();
      }
      setServosNormalized(cmdL_target, cmdR_target);
      break;
    }
    case FLARE: {
      float flare_cmd = 0.6f;
      setServosNormalized(flare_cmd, flare_cmd);
      double height_agl = fused_alt_msl - target_alt_msl;
      if (height_agl < TERMINAL_HEIGHT_M) {
        Serial.println("STATE: FLARE -> TERMINAL");
        state = TERMINAL;
      }
      break;
    }
    case TERMINAL:
      cmdL_target = 0.0f;
      cmdR_target = 0.0f;
      setServosNormalized(0, 0);
      if (landingDetected()) {
        Serial.println("STATE: TERMINAL -> LANDED");
        Serial.printf("FINAL ERROR: %.2f m\n",
                      distanceMeters(lat, lon, target_lat, target_lon));
        state = LANDED;
      }
      break;
    case LANDED:
      setServosNormalized(0, 0);
      break;
  }
  sendTelemetry1Hz();
  uint32_t loop_time = millis() - loop_start_ms;
  if (loop_time < 50) {
    delay(50 - loop_time);
  }
}

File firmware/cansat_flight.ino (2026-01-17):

/*******************************************************
 * AeroTrackNow CanSat – Teensy 4.0 Flight Code
 * Copy-paste into Arduino IDE and upload to Teensy 4.0.
 *
 * Features:
 * - State machine: BOOT -> WAIT_FOR_DROP -> WAIT_FOR_STABLE_DESCENT
 *                  -> GUIDED_DESCENT -> TERMINAL -> LANDED
 * - Predictive guidance toward target (uses predicted landing point)
 * - LoRa bidirectional:
 *     * receives TARGET once
 *     * receives RTK (RTCM3) continuously and forwards to GNSS UART
 *     * sends telemetry at 1 Hz
 * - GNSS: u-blox ZED-X20P over UART (Serial5 on Teensy 4.0)
 * - IMU: BNO085 over I2C (for drop detection accel spike)
 * - Barometer: BMP280 over I2C (pressure/temp + sink-rate)
 * - Two servos for parafoil steering
 * - NO buzzer
 *
 * Required libraries (Arduino Library Manager):
 * - RadioLib
 * - SparkFun u-blox GNSS Arduino Library
 * - Adafruit BMP280 Library (+ Adafruit Unified Sensor)
 * - Adafruit BNO08x
 * Built-in: Wire, Servo, SD
 *******************************************************/

#include <Arduino.h>
#include <Wire.h>
#include <Servo.h>
#include <SD.h>

// GNSS (u-blox)
#include <SparkFun_u-blox_GNSS_Arduino_Library.h>

// Sensors
#include <Adafruit_BMP280.h>
#include <Adafruit_BNO08x.h>

// LoRa (SX1262)
#include <RadioLib.h>

// ===================== PIN MAP (FINAL) =====================
// GNSS – ZED-X20P (U1)
static constexpr int PIN_GNSS_RX     = 21; // Teensy RX (connected to GNSS TX1)
static constexpr int PIN_GNSS_TX     = 20; // Teensy TX (connected to GNSS RX1)
static constexpr int PIN_GNSS_TPS    = 24; // optional input
static constexpr int PIN_GNSS_RTKFIX = 25; // optional input

// I2C – IMU + BMP280
static constexpr int PIN_I2C_SDA = 18;
static constexpr int PIN_I2C_SCL = 19;

// LoRa – SX1262 (U5)
static constexpr int PIN_LORA_CS    = 10;
static constexpr int PIN_LORA_DIO1  = 7;
static constexpr int PIN_LORA_RESET = 8;
static constexpr int PIN_LORA_BUSY  = -1; // set if wired; -1 if not connected

// SD card
static constexpr int PIN_SD_CS = 23;

// Servos
static constexpr int PIN_SERVO_LEFT  = 3;
static constexpr int PIN_SERVO_RIGHT = 4;

// ===================== BUILD OPTIONS =====================
static constexpr bool ENABLE_SD_LOGGING = true;  // set false to disable SD

// ===================== RADIO SETTINGS =====================
static constexpr float LORA_FREQ_MHZ = 433.0f;
static constexpr int   LORA_TX_DBM   = 14;   // adjust to comply with your rules
static constexpr uint32_t TELEMETRY_PERIOD_MS = 1000;

// ===================== GUIDANCE TUNING =====================

// Parafoil trim is adjusted in steps of 0.01..0.02
static constexpr float SERVO_TRIM = 0.0f;  
// + = pull LEFT slightly
// - = pull RIGHT slightly

// Normalized servo command range is -1..+1
static constexpr float KP_TURN = 0.9f;             // turning aggressiveness
static constexpr float MAX_TURN = 0.45f;           // clamp (avoid aggressive turns)
static constexpr float TERMINAL_HEIGHT_M = 8.0f;   // below this: servos neutral
static constexpr float CAPTURE_RADIUS_M = 1.0f;    // predicted landing close enough -> terminal

// Stabilization checks
static constexpr float STABLE_SINK_MIN = 3.5f; // m/s (positive downward)
static constexpr float STABLE_SINK_MAX = 7.5f; // m/s (positive downward)
static constexpr uint32_t STABLE_HOLD_MS = 2500;

// Drop detection (accel “event” threshold)
static constexpr float DROP_ACCEL_SPIKE = 8.0f; // m/s^2 deviation from 1g

// ===================== TELEMETRY PACKET =====================
#pragma pack(push, 1)
struct TelemetryPacket {
  uint8_t  msgType;          // 0x03
  uint32_t time_ms;

  int32_t  lat_e7;           // deg * 1e7
  int32_t  lon_e7;           // deg * 1e7

  int16_t  height_agl_dm;    // meters * 10 (AGL proxy = GNSS_alt_MSL - target_alt_MSL)

  uint16_t pressure_hPa_x10; // hPa * 10
  int16_t  temp_c_x10;       // C * 10

  uint16_t ground_speed_cms; // m/s * 100

  int16_t  servo_left_x1000; // -1000..1000
  int16_t  servo_right_x1000;

  int32_t  pred_lat_e7;      // deg * 1e7
  int32_t  pred_lon_e7;

  uint8_t  mission_state;

  uint16_t crc16;
};
#pragma pack(pop)

// ===================== INCOMING PACKETS =====================
#pragma pack(push, 1)
struct TargetPacket {
  uint8_t msgType;     // 0x01
  int32_t tgt_lat_e7;
  int32_t tgt_lon_e7;
  int32_t tgt_alt_cm;  // meters MSL * 100
  uint16_t crc16;
};
#pragma pack(pop)

// msg types
static constexpr uint8_t MSG_TARGET    = 0x01;
static constexpr uint8_t MSG_RTK       = 0x02; // payload = RTCM bytes
static constexpr uint8_t MSG_TELEMETRY = 0x03;

// ===================== STATE MACHINE =====================
enum MissionState : uint8_t {
  BOOT = 0,
  WAIT_FOR_DROP,
  WAIT_FOR_STABLE_DESCENT,
  GUIDED_DESCENT,
  TERMINAL,
  LANDED
};

MissionState state = BOOT;

// ===================== GLOBALS =====================
SFE_UBLOX_GNSS gnss;

Adafruit_BMP280 bmp;
Adafruit_BNO08x bno08x(-1);
sh2_SensorValue_t bnoValue;

// RadioLib Module(CS, DIO1, RST, BUSY)
SX1262 radio = new Module(PIN_LORA_CS, PIN_LORA_DIO1, PIN_LORA_RESET, PIN_LORA_BUSY);

Servo servoL, servoR;

File logFile;

// Target
bool targetReceived = false;
double target_lat = 0.0;
double target_lon = 0.0;
double target_alt_msl = 0.0;

// GNSS live
double lat = 0.0, lon = 0.0;
double gnss_alt_msl = 0.0;
double ground_speed = 0.0;      // m/s
double ground_track_rad = 0.0;  // radians

// Baro live
double pressure_hPa = 0.0;
double temp_c = 0.0;
double sink_rate = 5.5; // m/s (positive downward)
double last_baro_alt = 0.0;
uint32_t last_baro_ms = 0;

// Prediction
double pred_lat = 0.0, pred_lon = 0.0;

// Servo commands (normalized -1..+1)
float cmdL = 0.0f, cmdR = 0.0f;

// Timers
uint32_t lastTelemetryMs = 0;
uint32_t stableStartMs = 0;

// ===================== UTILS =====================
static uint16_t crc16_ccitt(const uint8_t* data, size_t len) {
  uint16_t crc = 0xFFFF;
  for (size_t i = 0; i < len; i++) {
    crc ^= (uint16_t)data[i] << 8;
    for (int b = 0; b < 8; b++) {
      if (crc & 0x8000) crc = (crc << 1) ^ 0x1021;
      else crc <<= 1;
    }
  }
  return crc;
}

static inline double metersPerDegLon(double lat_deg) {
  return 111111.0 * cos(lat_deg * DEG_TO_RAD);
}

static double distanceMeters(double lat1, double lon1, double lat2, double lon2) {
  const double R = 6371000.0;
  double dLat = (lat2 - lat1) * DEG_TO_RAD;
  double dLon = (lon2 - lon1) * DEG_TO_RAD;
  double a = sin(dLat/2)*sin(dLat/2) +
             cos(lat1*DEG_TO_RAD)*cos(lat2*DEG_TO_RAD)*sin(dLon/2)*sin(dLon/2);
  double c = 2 * atan2(sqrt(a), sqrt(1-a));
  return R * c;
}

static double bearingRad(double fromLat, double fromLon, double toLat, double toLon) {
  double dLat = (toLat - fromLat);
  double dLon = (toLon - fromLon) * cos(fromLat * DEG_TO_RAD);
  return atan2(dLon, dLat);
}

static float clampf(float v, float lo, float hi) {
  return (v < lo) ? lo : (v > hi) ? hi : v;
}
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

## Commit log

2026-01-06 Add SERVO_TRIM for parafoil trim adjustments
    Added parafoil trim adjustment constant for servo control.
2026-01-06 Update README with SERVO_TRIM adjustment details
    Added note about changing SERVO_TRIM in small steps.
2026-01-11 Re-enable guidance when drifting off course
    [cansat_flight.ino]
2026-01-14 Clarify USB serial ports in ground station docs
2026-01-14 Added PCB Files and Documents
    [AS-RTK2B-MICRO-F9P-L1L2UFLTH-00.step, CORE1262-868M.step, CanSat Schematic.kicad_pcb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]
2026-01-17 Apply servo trim and clarify radio bridge
2026-01-18 Added 3D models for each PCB
    [4754 BNO085 STEMMA QT.step, CanSat Schematic.kicad_sch, D24V10F3.step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]
2026-01-18 Add CanSat pre-launch power test sketch
2026-02-28 Revise pin assignments and connection status in PINOUT.md
    Updated optional pin connections for TPS and RTKFIX to indicate they are currently unconnected. Changed BUSY pin to 9 and added RXEN and TXEN pin assignments.
